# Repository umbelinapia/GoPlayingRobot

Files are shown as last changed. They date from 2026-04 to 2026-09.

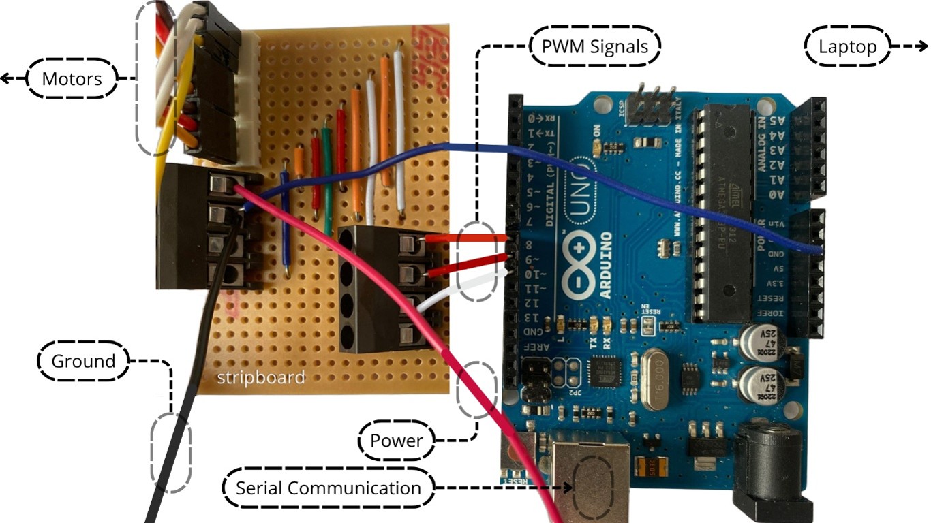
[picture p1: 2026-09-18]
evidence/labeled_arduino_stripboard_wiring.jpg

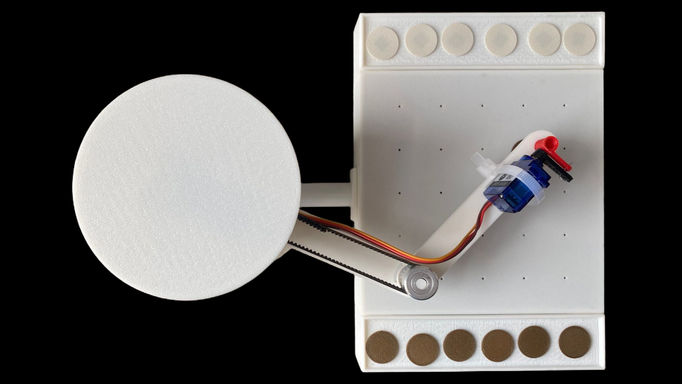
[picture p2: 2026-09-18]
evidence/robot_top_view_2.png

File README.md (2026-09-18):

# 3rd year Individual Project

## Project aim 
This report aims to build an autonomous robot that can master the ancient game of Go. This report focuses on designing, building, and validating a 3-DOF mechatronic robotic arm pick-and-place subsystem capable of reliably moving standard Go stones between specified board locations, using a defined coordinate interface and motion control.

## Project Objectives
1. Design and build a complete 3-DOF robotic arm electro-mechanical assembly, including CAD, actuator selection, mounting and joint structures capable of reaching all positions within the defined planar workspace.
2. Design and build a Go-stone gripper including its actuator, mounting interface to the arm, and required electrical connections capable of reliably picking up and placing Go stones.
3. Implement inverse kinematics to convert board coordinates into joint angles, enabling the end-effector to reach target positions within a positional accuracy of approximately 2 mm.
4. Develop and implement an interactive graphical user interface that converts user input into structured commands, transmitted to the motion controller under a second for execution in real-time.

## Board Interface
1. Clone the repository
2. Navigate to the python scipts Inside the software folder
3. Install dependencies listed in requirements.txt
4. Run the main code for the interface

## Motion controller
Upload `software/Arduino sketch/routines.ino` to your Arduino board using the Arduino IDE.

NOTE
Arduino Cloud sketches can also be found here:

🔗 https://app.arduino.cc/sketches/9923f9a1-adf1-4cbb-a925-ab8f35f5f6f3?view-mode=preview

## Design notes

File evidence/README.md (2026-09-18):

# Evidence

Supporting media for the Go-playing robot project: CAD renders, assembly photos, wiring diagrams, GUI screenshots, and design/flow diagrams. Imported from the local "supporting media content" folder.

| File | Label / Description |
|---|---|
| `wiring_diagram_arduino_servos.png` | Wiring schematic: Arduino Uno on a breadboard powered by USB (serial) and a separate 6V supply, driving three servos (Joint 1, Joint 2, Joint 3) via PWM, with a color-coded legend for ground, power, PWM signal, and serial lines. |
| `labeled_arduino_stripboard_wiring.jpg` | Photo of the real Arduino Uno wired to a stripboard, annotated with labels for Motors, PWM Signals, Laptop (USB), Ground, Power, and Serial Communication. |
| `system_block_diagram.png` | Hardware architecture block diagram: Python GUI sends serial commands over USB to the Arduino Uno, which sends PWM signals to the SCARA robot's three servos (Servo 1, Servo 2, Gripper servo); a separate power supply (gated by an emergency switch) powers the robot, which acts on the Go environment (board, bowls, stones). |
| `software_dataflow_diagram.png` | Software data-flow diagram showing three stages: (1) Graphical User Interface user input, (2) Arduino control system (command parsing → task logic → coordinate mapping → inverse kinematics → joint angles), (3) Output actuation to Servo 1, Servo 2, and the gripper servo. |
| `command_flowchart.png` | Logic flowchart for processing a `letter-number-letter` command (e.g. `B3P`), branching on the trailing R (release/place stone) or P (pick stone) code and on space/stone availability to the left or right, ending in `return to standby`. |
| `cad_dimensioned_cross_section.png` | Dimensioned CAD cross-section drawing of the arm/base assembly with key measurements in mm (110, 90, 140, 44, 22, 32, 10.5). |
| `robot_isometric_view.png` | Isometric photo of the fully assembled robot: cylindrical rotating base, boom arm with pulley/belt drive, gripper servo with magnetic end-effector, board with rows of stone slots, and a battery pack in a drawer under the base. |
| `robot_top_view_1.png` / `robot_top_view_2.png` | Top-down photos of the assembled robot in two arm positions, showing the rotating base disc, timing belt/pulley drive along the boom, and the blue micro servo end-effector positioned over the stone board. |
| `pulley_belt_closeup.png` | Two close-up shots of the GT2 timing pulley and belt at the arm's rotating joint. |
| `gripper_servo_horn_positions.png` | Side-by-side photos of the gripper servo horn at three rotation angles, showing the end-effector's release / neutral / pick-up positions. |
| `labeled_component_overview.png` | Annotated photos identifying the robot's main parts: Casing, Bowl, Stone, Timing belt and pulley, End-effector, and Power switch. |
| `low position.png` / `mid position.png` / `high position.png` | SolidWorks cross-section views of the vertical plunger/rod at its three stroke positions (fully lowered, mid-stroke, fully raised) within its housing. |
| `side slit view in casing.png` | SolidWorks assembly cross-section (side view) showing the full internal layout: servo stack, drive shaft, belt/pulley, and linkage inside the casing. |
| `go_gui_empty_board.png` | Screenshot of the "Responsive 5x5 Go Board" Python GUI with an empty board and the Arduino connection shown as ENABLED / "Sending to robot". |
| `go_gui_board_with_stones.png` | Screenshot of the same GUI mid-game, with black and white stones placed on the board and the Arduino link still ENABLED. |
| `target_coordinates_plot.png` | Plotted coordinate map (mm) of board target points, bowl target points, and the origin (0,0), with board and side-bowl outlines, used for the robot's placement coordinate calibration. |

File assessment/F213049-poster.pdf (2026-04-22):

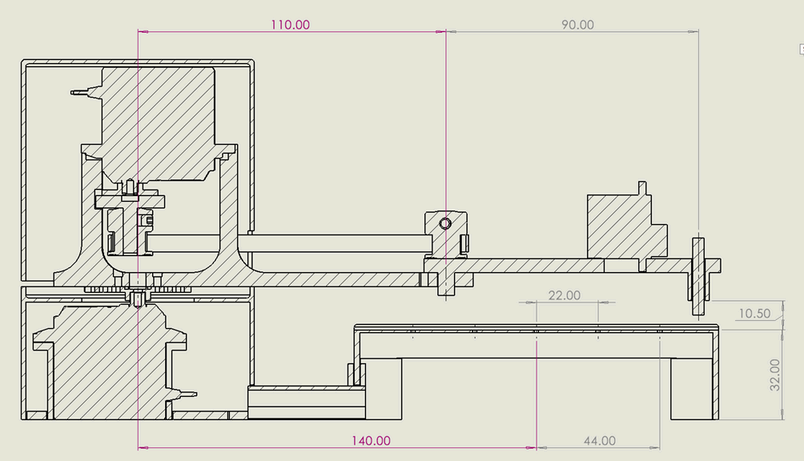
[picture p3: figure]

Design and build a complete 3-DOF robotic arm electromechanical assembly capable of reaching all 25 board positions within the planar workspace.
Design and build a Go-stone gripper capable of reliably picking up and placing stones.
Implementinverse kinematics converting board coordinatesto joint angles with ≈ ±2mmpositional accuracy.
Develop an interactive graphical user interface transmitting commandsto themotion controllerin under one second.

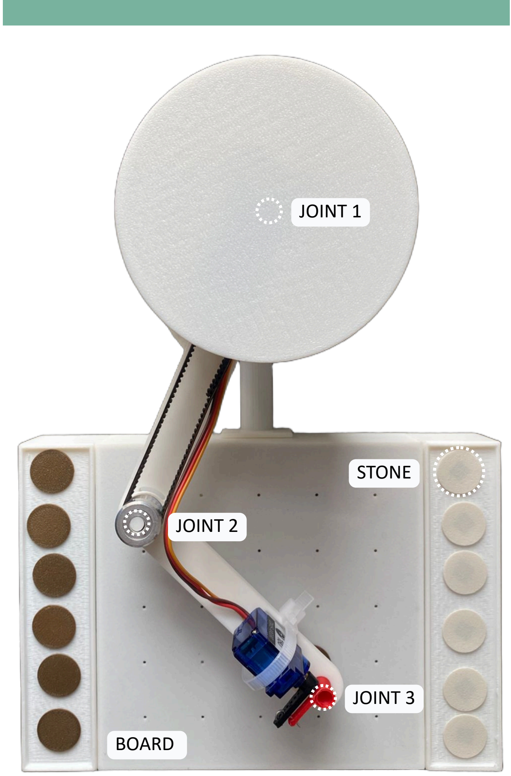
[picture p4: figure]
JOINT 1; JOINT 3; BOARD; STONE; JOINT 2

PLA deformation → slack and backlash → low accuracy Open-loop control → no feedback → no correction Limited workspace → 2 unreachable positions
Magnetic gripper → standardGo stonesincompatibility limited verticalrange → standardGo stonesincompatibility

3-DOF SCARA robotic armwith RRP joint configuration. Controlled by anmicrocontroller, operated through aGUI.Joint 2 is operated remotely with a timing belt and pulley drivingmechanism. Robot is at a fixed distance fromthe board.

Despite the resurgence of physical board games, a fundamental barrier persists: you need another player. Research shows physical materiality is a key part of the game experience that digital formats cannot replicate. Drawing upon those challenges, this report aims to build an autonomous robot that can master the ancient game ofGo.

It is an ancient Chinese board game conceived more than 2,500 years ago. The goal is to capture more territory than your opponent. The players do so each in turn by placing stones on the intersections of the board. the board can vary in size but the game is commonly played on a 19x19 board. It has very simple rules and concepts, and yet it is considered by many people to be the world’s greateststrategic game.

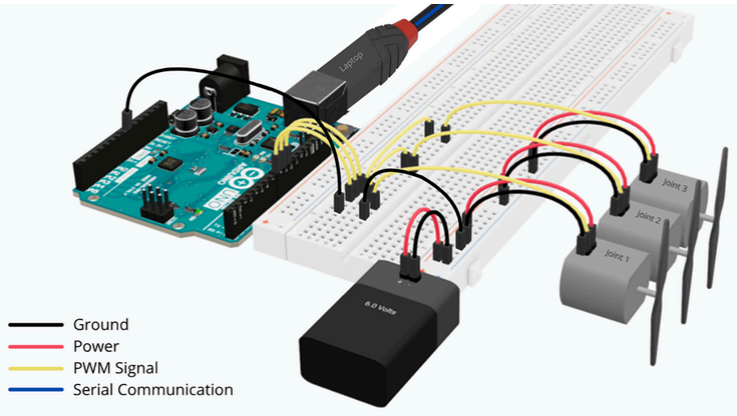
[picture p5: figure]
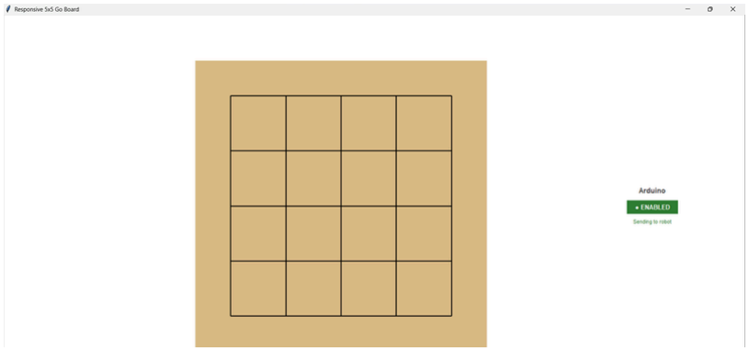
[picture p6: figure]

1.Computer vision forreal-time board state detection 2.Go AI engine integration forfull autonomy 3.Closed-loop feedback controlto improve precision 4.Redesigned end-effectorforstandardGo stones

P U R P O S E | M OT I VAT I O N

# S P E C I F I C AT I O N S

# A R C H I T E C T U R E

# C I R C U I T

# U S E R I N T E R FA C E

# E N D - E F F E C TO R

# R E S U LT S

L I M I TAT I O N S | F U T U R E W O R K

100% pick successrate achieved under controlled conditions (end-effector directly above stone)
Positional accuracy varied due to backlash atJoint 2 ,the ±2mm target was not consistently achieved Adjustablemotion speed via Arduino,set asslow
All 25 board intersectionsreached within defined workspace
links | lengths | joints | range | type | motor
Link 1 | 110mm | Joint 1 | 270° | revolute | DSS-M15S
Link 2 | 90mm | Joint 2 | 270° | revolute | DSS-M15S
Link 3 | 15mm | Joint 3 | 5mm | prismatic | DMS-MG90

# W O R K F LO W

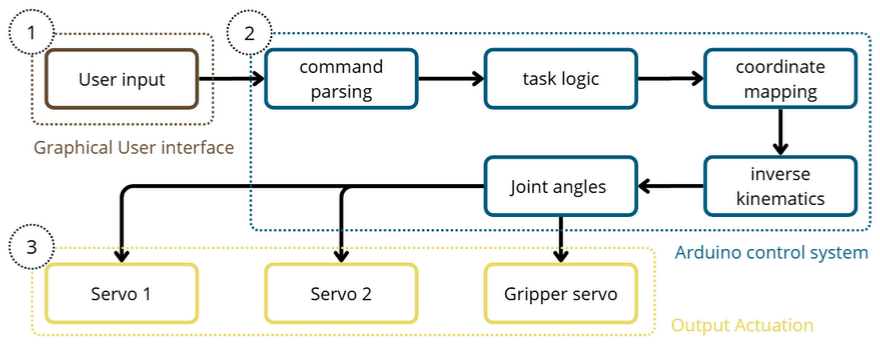
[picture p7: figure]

1.User clicks a board intersection on the PythonGUI
2.GUI formats a command (e.g. B3P = column B,row 3, Place) 3.Command sentto Arduino viaUSB serial communication 4.Arduino parses command and determines action 5.Targetmapped to Cartesian coordinates
6.Inverse kinematics computesjoint angles
7.PWM signalssentto servos, armmoves and executestask

A Python Tkinter graphical user interface was developed to control the robotic arm. The interface displays an interactive 5×5 Go board. The user places or removes stones by left or right clicking on board intersections. Each click generates a serial command (e.g. B3P)transmitted instantly to the Arduino.

Three servo motors are controlled by an Arduino Uno via PWM signals. Each servo is powered by an external 6V AA battery supply, with a common ground shared between the Arduino and power supply. Permanent connections are soldered to a stripboard to ensure reliability. The Arduino connectsto the laptop viaUSB forserial communication with theGUI.

# D E V I C E

# ProjectGrandmaster: An Autonomous RoboticOpponentforGo

### Robotics, Mechatronics and Control Engineering MEng 25WS50META Supervised by Massimiliano Zecca Wolfson School of Mechanical, Electrical and Manufacturing Engineering

Figure 2: End-effector Mechanism | Figure 1:Go Playing Robot

### WHAT ISGO?

### WHYDO WENEEDA ROBOT?

### WHAT ARE THEOBJECTIVES?

This report aims to build an autonomous robot that can master the ancient game ofGo.

### WHAT IS THE AIM?

Figure 4: SystemCircuit Model

Figure 3: System Workflow

Figure 5: GUI BoardDisplay

The end-effector combines Joint 3 and the gripping mechanism into a single unit. A servo converts angular motion into vertical movement via a horn and thin rod. Atthe bottom sits a permanent magnet for passive gripping of magnetic Go stones. It operates in three states:

(a) Low: picking position
(b)Hover: carrying/travelling position (c)High: dropping position

Table 1: Robot Specifications

Figure 6: Slice of Assembly Drawing

Umbelina Pia Selva F213049

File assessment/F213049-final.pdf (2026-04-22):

Wolfson School of Mechanical, Electrical and Manufacturing Engineering

## Individual Project Final Report

ID Number: F213049

Programme: Robotics, Mechatronics and Control Engineering

Module Code: 25WS50META

Project Title: Project Grandmaster: An Autonomous Robotic Opponent for Go.

Abstract:

This report presents the design and implementation of an autonomous robotic system capable of acting as a partial physical opponent for the board game Go. The primary aim was to develop a 3 degree of freedom SCARA based robotic arm capable of reliably performing pick and place operations of Go stones on a Go board.

The system was brought to life through a combination of mechanical design, hardware implementation and software control. A SCARA configuration was selected for its suitability in such tasks, and the robot was made to meet workspace and precision requirements. Forward and inverse kinematics were explored to compute joint angles from board coordinates. Control was achieved using a micro controller, with formatted commands converted from the user input by a Python Graphical User Interface.

The robot demonstrated reliable operation across the defined workspace. It achieved consistent pick and place operations with the gripper, reaching 100% success rate under specific conditions. With an efficient inverse kinematics algorithm, the system maintained good repeatability throughout experiments. However, the system suffered minor precision errors due to mechanical backlash. Additional limitations included lack of feedback control and flexibility of the device.

In conclusion, the project achieved its objective of developing a functional robotic Go opponent at a low-level. While the output has successfully met most objectives, the integration of computer vision and an AI Go engine is required to achieve full autonomy.

## 1 Table of Contents

## 2 Introduction

2.1 Project background
Amongst many other board games, the game of Go stands out for its ancient origins. Go, as it is known in Japan, is an ancient Chinese board game conceived more than 2,500 years ago [1], and it is believed to be the oldest board game that is still played today. Also known as Weiqi (圍棋) in China meaning "surrounding game", the goal is to capture more territory than your opponent. The players do so each in turn by placing stones on the checkered lines of the board. Although, the board can vary in size depending on the level of the player, the game is commonly played on a 19x19 board. It has very simple rules and concepts, and yet it is considered by many people to be the world’s greatest strategic game, far surpassing Chess in its complexity [2]. It was brought to the UK from Japan over a century ago and has since gained in popularity.

2.2 Project context
Developments in technology have progressively shifted board games, such as Go, on digital platforms. Modern video games offer many advantages over board games. Players can instantly access a wide variety of games at any time and connect with opponents globally without the constraints of location or time. However, there has recently been renewed interest in physical board games. This resurgence in popularity has led to their increasing commercial success [3]. Despite this rising phenomenon, there remains a paucity of evidence on the reasons why players would rather choose board games over online ones. It is important to note that the relative preference of board gaming is debated in the literature. It can be argued that playing on a physical board offers a tactile and sensory experience sought by players. Recent evidence shows that the materiality provided by physical components is a key element in the player experience that digital formats cannot replicate [4]. On the other hand, board games also present serious drawbacks. The main limitation lies in requiring another player. Players often find themselves unable to engage with board games particularly when no suitable opponent is available. This creates a challenge, leading many to seek a form of the game that combines the advantages of both physical and digital versions. Restoring the authenticity of board games whilst no longer relying on the presence of a fellow player. A solution that can provide a constant, capable and physical opponent allowing the gaming experience to be enjoyed to its fullest.

2.3 Project aims and objectives
Drawing upon the challenges associated with board games, this report aims to build an autonomous robot that can master the ancient game of Go. This report focuses on designing, building, and validating a 3-DOF mechatronic robotic arm pick-and-place subsystem capable of reliably moving standard Go stones between specified board locations, using a defined coordinate interface and motion control. It is beyond the scope of study to encompass the implementation of an intelligent computer vision system with a powerful, pre-existing AI game engine.

The main objectives of the project were to:
1. Design and build a complete 3-DOF robotic arm electro-mechanical assembly, including CAD, actuator selection, mounting and joint structures capable of reaching all positions within the defined planar workspace.
2. Design and build a Go-stone gripper including its actuator, mounting interface to the arm, and required electrical connections capable of reliably picking up and placing Go stones.
3. Implement inverse kinematics to convert board coordinates into joint angles, enabling the end-effector to reach target positions within a positional accuracy of approximately 2 mm.
4. Develop and implement an interactive graphical user interface that converts user input into structured commands, transmitted to the motion controller under a second for execution in real-time.

2.4 Report description
This report begins with a brief literature review, examining related work in the field and possible robot architectures fit for this project. It then proceeds to the main body, which is organised into four chapters. The first section of this report will examine the model of the system including design constraints, overall structure, links and joints, kinematic model, and inverse kinematics of the robot. The second part will be concerned with the hardware of the project. Specifically, the selection and development of key components such as the CAD links, actuation system, transmission mechanism, end-effector, power supply, and control hardware. Chapter three will begin laying out the implementation of the control system, including the Arduino setup, and it looks at how the target coordinates are mapped, movement sequences operated and serial command handled. This is followed by the description of the Python-based playing interface as well as the workflow of the overall system. The last section will present the results of the project, focusing on the limitations and considering the possible future developments of the project.

## 3 Literature review

3.1 Related work
Whilst some research has been carried out on other board game playing robots, only a limited number of Go playing robots have been identified. One of which is a commercialised device, called senseRobot [5]. It features an AI engine integrated in a robotic arm, which provides a learning platform for beginners and children. The robot also covers a wide variety of other board games such as Gomoku, Xiangqi and chess. Similarly, a great deal of previous research into board game playing robots has focused on chess [6,7,8,9,10,11]. A number of these studies focus on the implementation of a chess engine with a robot, that has not been designed for chess, to offer a physical opponent. In order to deliver the task some of the researchers have opted to work with either a Cartesian robot, a custom 6 DOF robot, or a collaborative UR5 robot. Despite having different mechanical structures, these systems share the same components, automatic detection and recognition of the board enabled with a vision system and learning algorithms. Such approaches are relevant because chess, like Go, is an ancient board game played on a wood board around the same size. However, these studies have failed to address the inclusion of a Go stone specific end-effector and the implementation of a Go engine in a manipulator. A search of the literature revealed studies which cover Go engines alone [12,13]. The algorithms use reinforcement learning to play against opponents and are deployed on board games interfaces when facing a physical player. Their performance is unmatched compared to human’s success rate and reach levels far beyond worldwide professional players. But up to now, far too little attention has been paid to implement these same AI agents into a physical game-playing robot. Many hobbyists have attempted to bridge the gap however none of them qualify as academic peer reviewed papers and therefore this idea has received scant attention in the research literature.

3.2 Robot architecture
Given the lack of groundwork for Go playing robots, plenty of freedom is given with regards to the mechanical design. From a mechanical perspective, the system can be fundamentally characterized as a pick and place device. Research has been led to better understand the mechanisms of different robotic structures and their underlying advantages depending on the required task [14,15,16]. These studies offer a classification of robotic architecture and their uses. They suggest that there are five main robot types: cylindrical, articulated, SCARA, Cartesian and Delta robots among many others. Out of which, three configurations emerge from the studies mentioned so far used to perform pick and place operations: specifically, the SCARA, Delta and Cartesian robots. There seems to be some evidence to indicate they supply high speed and good repeatability making them ideal for such tasks. A number of studies have postulated that Delta robots despite having low payload capacities and a small workspace, have extremely high-performance speed and precision [17,18,19]. These aspects theoretically lend themselves well for picking and dropping stones on a board. However, their parallel-link structure introduces significantly greater kinematic complexity compared to other configurations, making both implementation and control more challenging. In contrast, other writers have adopted Cartesian architectures instead [20,21,22]. Together these studies provide important insights into the benefits and downsides of this configuration. Cartesian robots have proven to be equally good in both speed and precision. Additionally, it is noted that their rigid axis allows them to sustain much higher loads. However, this comes at the price of size, which impairs the workspace and in turn limits the reach of the end-effector. Although the dynamics fit the gameboard narrative well, in a Go game setting, the rigid axes might interfere with the human opponent’s personal space while playing. Along the same lines, many recent studies have also shown that SCARA robots are ideal for pick and place purposes[23,24,25]. Their work demonstrates that this configuration is consistent with previous ones, showcasing high speed and precision especially for planar tasks, with a moderate payload capacity. Such characteristics make them highly effective for Go-based tasks, which are performed over a flat even surface. However, there are noted flaws in the vertical axis, having limited reach and low flexibility. But these constraints are acceptable for the current application, where motion is largely planar and height variation is minimal. Overall, SCARA robots provide a more compact and accessible design than Cartesian systems, and a simpler, more practical implementation compared to Delta configurations. In all the studies reviewed here, precision is recognised asthe key indicator for pick and place tasks. Given all the design trade-offs, cost and existing literature on Go playing robots, considerable evidence has accumulated to show that SCARA robot structures are best suited for this project.

## 4 Methodology

4.1 Model

4.1.1 Constraints
To inform the design of the SCARA robot, the physical dimensions of the board and stones were identified, as these defined the system requirements. It should be noted that, for the purposes of this project, Go related materials were homemade and therefore did not fully reflect traditional designs. This project is focused on the second smallest Go board size, a 5x5 Go board. Each twenty-five playable position on the board was an intersection of a grid formed by a windowpane pattern. The board dimensions were as follows 130 mm in width and length, with row spacing of 23 mm and column spacing of 22 mm, resulting in a slight asymmetry. The Go stones used in this project have a diameter of 18.0 mm and are 1mm thick, resulting in a negligible mass. This is important because weight of the Go stones and their dimension influenced directly the design of robot and its the end-effector. Additionally, stones were stored in bowls during gameplay, which has been considered in this design.

Based on these constraints, the manipulator was required to have a minimum reach of at least 135 mm to fully cover the board. Furthermore, the robot was required to achieve a precision ±2 mm to accurately pick and drop stones at specific intersectionsin order to avoid overlapping stones. Finally, it was required to have a minimum vertical range of 5 mm to allow for clearance above board and stones during manipulation, meanwhile payload requirements remained minimal.

4.1.2 Structure
To cater for all constraints, the adopted design conformed to a SCARA-based structure with an open kinematic configuration. The robotic arm consisted of a series of links connected by three joints, forming an open-kinematic chain. One end of chain was connected to the base, while the other end was equipped of an end -effector to manipulate Go stones [Fig 1]. The system followed an RRP joint configuration which provided three degrees of freedom. The two first joints were revolute, enabling rotational motion, while the third one was prismatic, providing linear motion [Fig 2]. This arrangement enabled planar motion in the horizontal plane combined with vertical motion for picking and dropping stones.

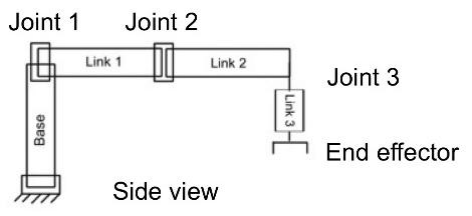
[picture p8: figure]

4.1.3 Links and joints

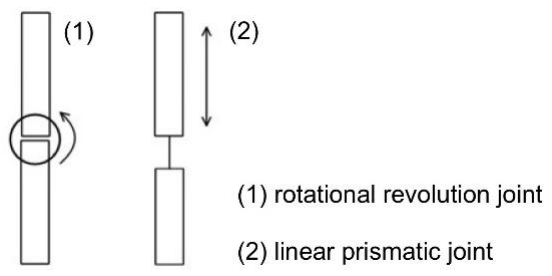
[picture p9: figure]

The manipulator workspace was determined by the number of joints, their geometric arrangement, and the link dimensions. In this design, the link lengths were selected to ensure that the robot can

Figure 1: Scara robot configuration | Figure 2: Joint configurations

cover the full board. The combined lengths of the two first links allowed the wrist frame to reach all twenty-five intersections. Additional length in the links was considered for the robot base to be positioned at an offset from the board rather than directly adjacent to it. Overall, the link lengths were chosen to maximize reachable workspace while keeping the structure compact and reducing the torque required for each revolute joint.

For the first two links, the planar RR reachable workspace, where r the distance from the base to the end-effector, was:

∣ L1 − L2 ∣≤ r ≤ L1 + L2 | 20 ≤ r ≤ 200 mm

The model reached points at distances between 20 mm and 200 mm from the base. Only the offset between the base and the board would determine whether the intersections are within the reachable workspace. As it were, the base frame of the robot stood 140mm away from the centre of the Go board. As a result, any desired target point on the board lied within the reachable workspace of the manipulator. To maximise the workspace, each revolute joint was designed with a rotational range of 270° [Figure 3], allowing the manipulator to access a wider set of positions such as the stones contained in the bowls.

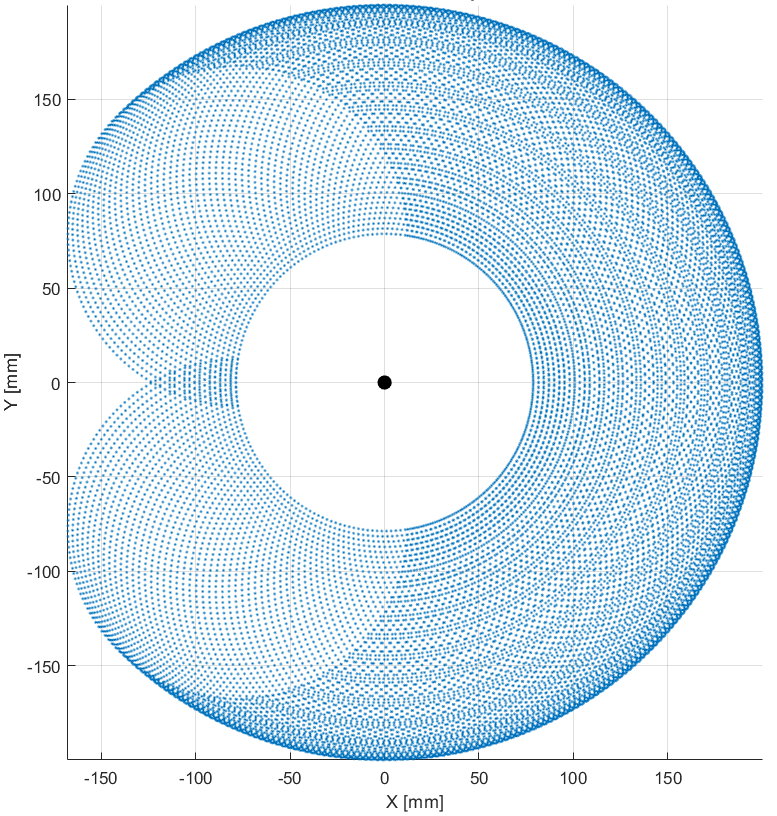
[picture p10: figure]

Figure 3: Reachable workspace

Table 1. Dimensions

Links | Lengths | Units | Joints | Range | Units
1 | 110 | Millimetres | 1 | 270 | Degrees
2 | 90 | Millimetres | 2 | 270 | Degrees
3 | 15 | Millimetres | 3 | 5 | Millimetres

4.1.4 Kinematics
Given a set of joint angles, the position and orientation of the tool frame relative to the base frame of the manipulator were computed using forward kinematics. The composition of the link parameters of the open-chain manipulator was as follows:

The position of the wrist frame relative to the base frame was expressed as:

x = L1 cos(θ1

) + L2 cos(θ1 + θ2

) = 110 cos(θ1

) + 90 cos(θ1 + θ2

)

y = L1 sin(θ1

) + L2 sin(θ1 + θ2

) = 110 sin(θ1

) + 90 sin(θ1 + θ2

)

z = 50 − d3

The overall transformation from the base frame to the tool frame was obtained by multiplying the homogeneous transformation matrices of each joint:

T0

3 = [

cos(θ1 + θ2

) − sin(θ1 + θ2

) 0 L1 cos(θ1

) + L2 cos(θ1 + θ2

)
sin(θ1 + θ2
) | cos(θ1 + θ2
) | 0 | L1 sin(θ1

) + L2 sin(θ1 + θ2

)
0 | 0 | 1 | 50 − d3
0 | 0 | 0 | 1

]

Where:

L1 = 110mm

L2 = 90mm

T0

3 = [

cos(θ1 + θ2

) − sin(θ1 + θ2

) 0 110 cos(θ1

) + 90 cos(θ1 + θ2

)
sin(θ1 + θ2
) | cos(θ1 + θ2
) | 0 110 sin(θ1

) + 90 sin(θ1 + θ2

)
0 | 0 | 1 | 50 − d3
0 | 0 | 0 | 1

]

Table 2. DH parameters of SCARA robot

Link number | Link length [mm] | Twist angles | Link offset [mm] | Joint angles
i | ai | αi | di | Θi
1 | 110 | 0 | 50 | Θi1
2 | 90 | 0 | 0 | Θ2
3 | 15 | 0 | d3 | 0

4.1.5 Inverse Kinematics
Inverse kinematics was used to determine the joint variables required for the manipulator to reach a desired position in the task space. In this project, inverse kinematics was applied to map the intersections of the Go board into corresponding joint space configurations. For this purpose, only the first two joints were considered, as they fully defined the position in the xy-plane. The third joint did not influence planar motion and was therefore omitted in the analysis.

Let the desired wrist position be (x,y). The radial distance from the base was:

r

2 = x

2 + y

2

Using the law of cosines, the second joint angle was given by:

cos(θ2

) =

r

2 − L1

2 − L2

2
2L1L2

θ2 = arccos (
r

2 − L1

2 − L2

2
2L1L2

)

The first joint angle was then obtained as:

θ1 = atan 2(y, x) − atan 2(L2 sin(θ2

) , L1 + L2 cos(θ2

))

Two possible solutions existed for θ1 and θ2, corresponding to the elbow-up and elbow-down configurations of the manipulator. Both solutions were valid as they lied within the joint limits.

4.2 Hardware

4.2.1 Links CAD and 3d printing
To put all those theoretical calculations into practice and bring the SCARA robot to life, the system was designed to meet the defined requirements. The parts required to achieve the desired link lengths were designed using SolidWorks and manufactured using Bambu Studio on Bambu 3D printers. They were manufactured using PLA due to its ease of printing, low cost, and sufficient stiffness for the low-load application. The links were designed as lightweight rectangular beams [Figure 4] to provide sufficient stiffness while minimising mass. Thereby reducing the torque required at each joint, allowing for smaller and more efficient actuators. The masses of the individual links were determined to be 18g, 10g, and 1g for links 1, 2, and 3 respectively. All parts of the assembly model can be found in the appendix.

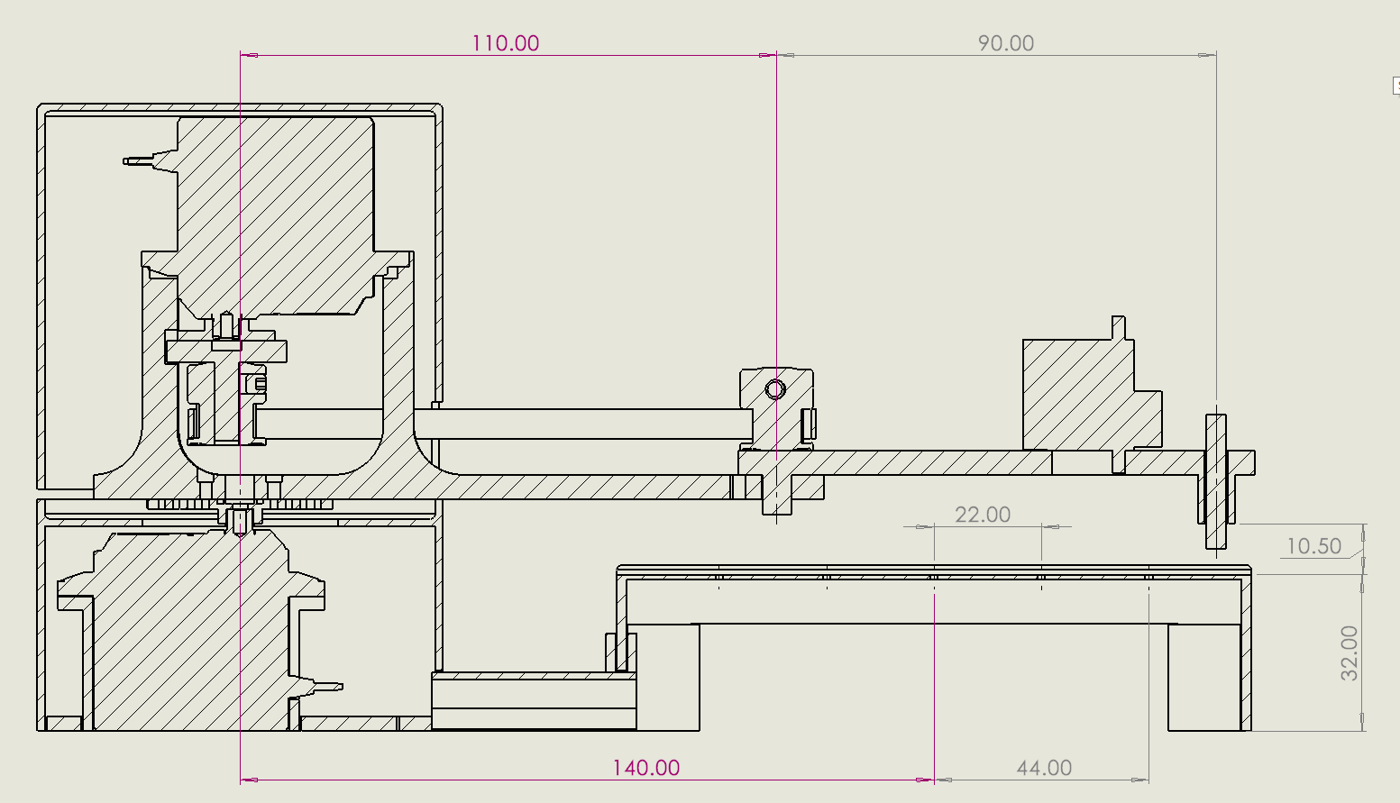
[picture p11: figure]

Figure 4: Assembled CAD Side view

4.2.2 Actuation system
The selection of actuators was guided by the torque and range of motion required for the manipulator. For a robot joint, the required torque is the sum of the moments caused by all loads acting beyond that joint [equation 1]. τ is the torque and d represents the perpendicular distance from the joint axis. F is the sum of all the forces acting on an object, and g the gravitational force. In this case, the main force acting on the arm was the weight :
τ = F ∗ d | F = m ∗ g | τ = m ∗ g ∗ d

For joint 3, the mass of the combined end-effector and payload was negligible therefore only a small torque was required [Tab 4]. However, the same could not be said for joint 1. The static torque required at joint 1 was estimated from the masses of the links, end-effector, and payload, along with their distances from the joint axis. It was calculated as follows:

τ1 = m1 ∗ g ∗

L1
2

+ m2 ∗ g ∗ (L1 +

L2
2

) + m3 ∗ g ∗ (L1 + L2)

Where:
m1= mass of Link 1 and the motor at Joint 2 = 18 + 72 = 90 grams
m2= mass of Link 2 and the pulley at Joint 2 = 10 + 10 = 20 grams
m3= mass of Link 3, the servo at Joint 3, and the end-effector magnet = 1 + 9 + 2 = 12

τ1 = 90 ∗ g ∗

110
2

+ 20 ∗ g ∗ (110 +

90
2

) + 12 ∗ g ∗ (110 + 90) = 1.05 kg ∗ cm

The selected actuator provided a stall torque of 11.5 kg*cm. This provided a sufficient safety margin for reliable operation while accounting for friction and assembly tolerances. The same actuator was selected for joint 2, where the torque requirements were lower. Additionally, these motors were chosen to satisfy the desired operating range of 270 degrees.

Table 3. Actuator selection

Model | Type | Weight | Stall Torque | Operating Voltage | Operating Range
DMS-MG90 | Servo | 9g | 1.8 kg / cm | 4.8-6V | 60° degrees
DSS-M15S | Servo | 72g | 13.5 kg / cm | 4.8-7.2V | 270° degrees

4.2.3 Transmission mechanism
To reduce the load acting on Joint 1, the actuator responsible for driving Joint 2 was positioned above Joint 1 rather than directly on Link 1. As a result, a transmission mechanism was required to transfer motion from the motor to joint 2 remotely. To achieve this, a timing belt and pulley system was implemented to the design. To maintain 1:1 transmission ratio and ensure that angular displacement was directly transferred from the motor to joint 2, identical GT2 models with a diameter of 12.22mm were used at both ends. This pulley profile was specifically designed to minimise backlash and provide accuracy. Finally, the centre distance between the two pulleys was set to 110 mm. Based on this configuration, the required belt length [eq 3] was calculated to ensure proper tension, reduce backlash and avoid poor transmission. This was particularly important given the precision requirements of the manipulator.

L = 2 ∗ C + 1.57 ∗ (D + d) +

(D − d)

2
4 ∗ dC = 258 mm

Where:
C = Centre to centre distance = 110 mm D = d = Diameter of pulley = 12.22 mm

L = Length of timing belt

4.2.4 End-Effector design
The end-effector featured both the Joint 3 and the gripping mechanism into a single unit. This design enabled the motor to perform both vertical motion and pick-and-place operations. The motor’s angular motion was converted into vertical motion via a servo horn through a thin rod connected to link 3. In which lay within, at the bottom, a magnet that carried out the ‘gripping’ operation [Figure 5]. It was a passive system which only complied with light magnetic stones. The end effector operated in three distinct states. The low position [a] where the end-effector was brought into contact with the stone, allowing the magnet to attract and pick it up. The hovering position [b] where the end-effector was raised slightly above the board, enabling safe horizontal transport of the stone without interference with other pieces. And finally, the top position [c] where the end-effector was lifted further upward, causing the stone to lose contact with the magnet.

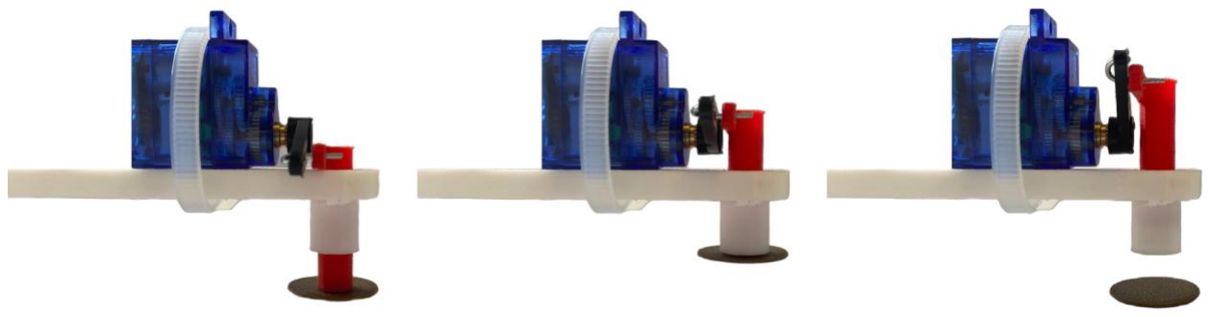
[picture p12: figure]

(a) Low | (b) Hover | (c) High

Figure 5: End-effector mechanism

4.2.5 Power supply
The system was powered by four AA batteries, providing a total supply voltage of approximately 6V. This voltage was suitable for driving the selected servo motors, which operated within a range of 4.8 to 7.2 V. The system could easily be powered on and off with the switch provided on the battery container.

4.2.6 Control Hardware
The servo motors were controlled by an Arduino Uno, which generated the required PWM signals to control the angular position of each joint. Each servo had 3 wires: power, ground and signal. The signal wire was connected to the Arduino via signal pins, while power and ground wires were supplied by the external power supply [Figure 6]. A common ground was maintained between the Arduino and the power supply to ensure proper signal reference. Lastly, the Arduino Uno was connected to a laptop via a USB cable, enabling the transmission of inputs from the playing interface.

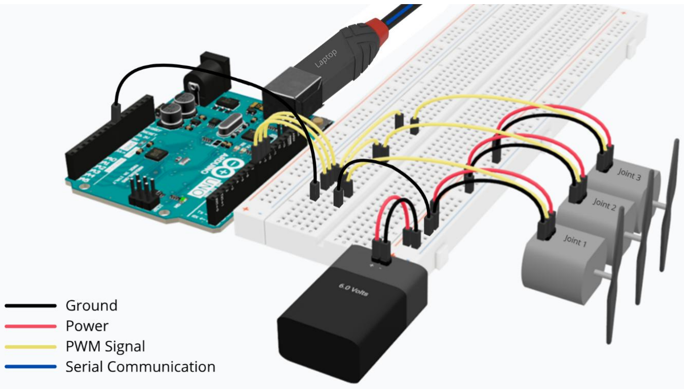
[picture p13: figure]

Figure 6: Circuit model

4.2.7 Circuit and assembly
The electrical system of the device consisted of three servo motors, an Arduino microcontroller, and a dedicated power supply. To ensure a reliable and robust circuit, the permanent connections were soldered to a stripboard. This reduced the risk of loose connections. Cable management was also considered in the design to reduce clutter and improve ease of transport. Routing paths were incorporated into the CAD model to conceal and secure cables within the structure [Figure 7].

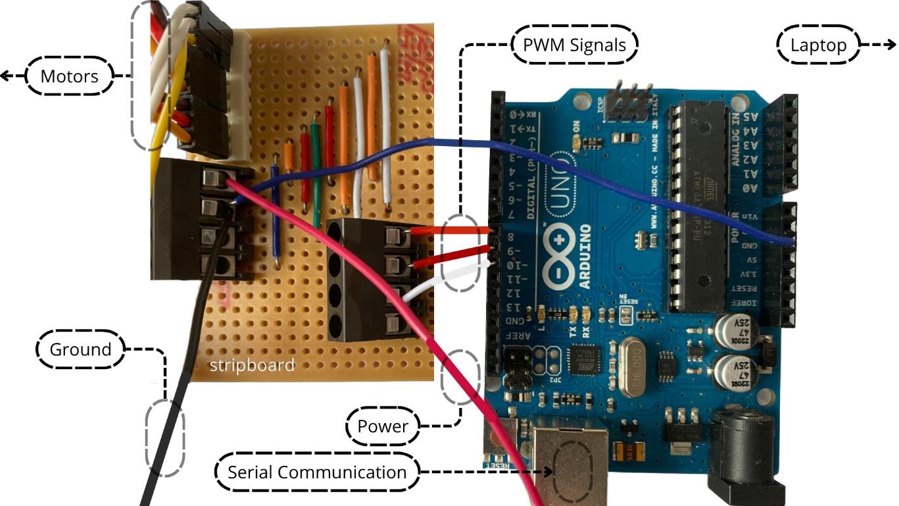
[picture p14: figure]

Figure 7: Circuit assembly

Finally, upon assembly, the components formed the complete SCARA robot system. The links, joints, and actuators were securely fastened using either cable ties, tight fits or screws and nuts. A casing was added to cover the components [Figure 8]. Although initially intended for visual appearance, the casing also contributed to the safety of the device.

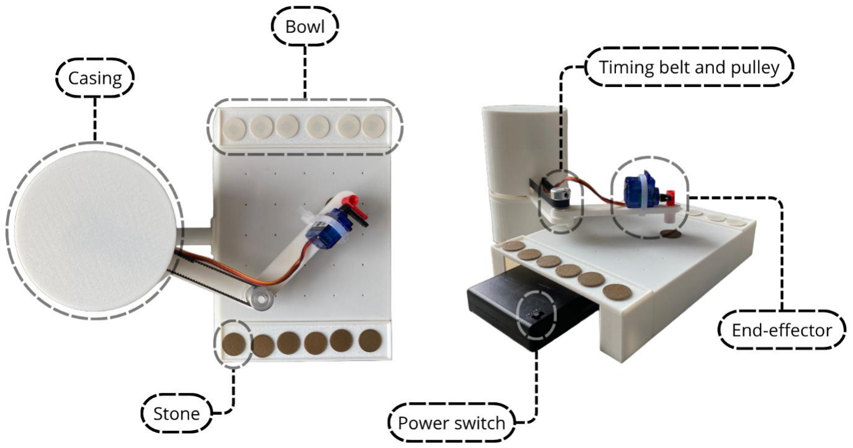
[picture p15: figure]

Figure 8: Go playing SCARA Robot

4.3 Software

4.3.1 Arduino IDE
To control the three motors connected, the SCARA robot was programmed using Arduino IDE. This environment was used to write, compile and upload code to the Arduino board as well as send commands through the serial monitor [Figure 9].

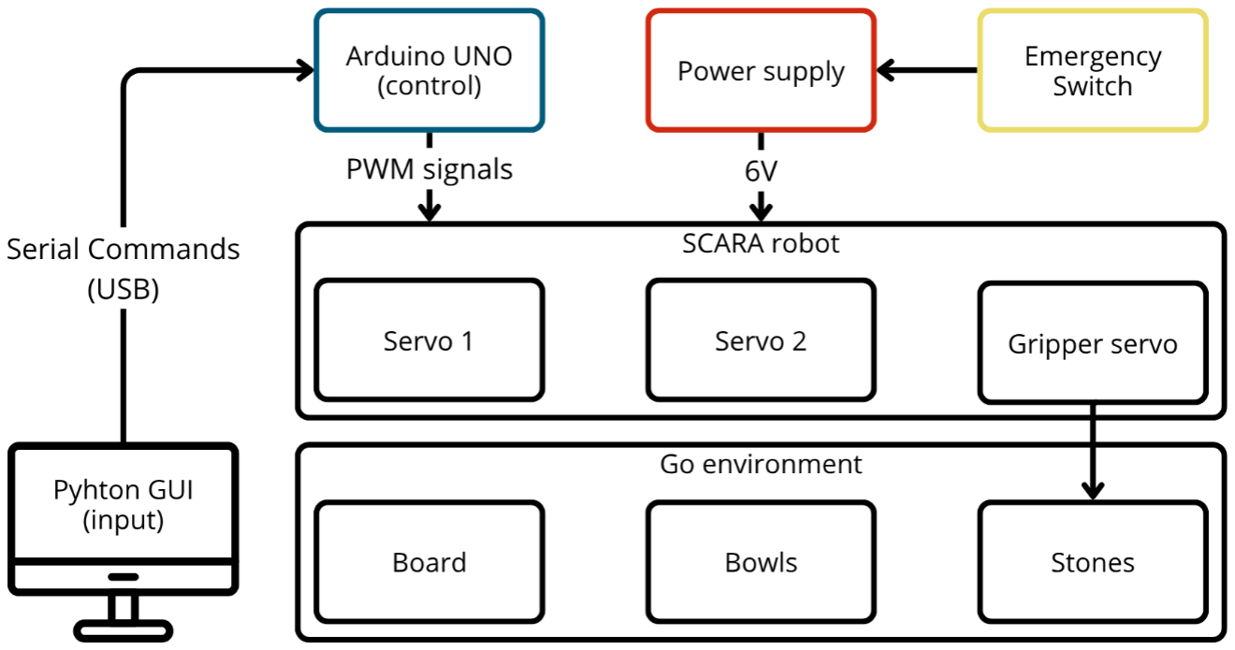
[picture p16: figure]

Figure 9: System Architecture

The project was separated into header files [Figure 10] to make the project easier to maintain and debug. In total, the folder consisted of seven files: the main Arduino .ino file and three pairs of .cpp (source) and .h (header) files. The .cpp files each contained a specific implementation, while the corresponding .h files declared functions and shared variables, making them accessible across different files. They can all be found in the appendix.

Figure 10: Project files

4.3.2 System setup
The main file provided the foundation for the rest of the environment. In included an inverse kinematics model was implemented to enable the robotic arm to reach specific target positions on the board. Before this could be applied, the required libraries were imported to support the mathematical computations needed to determine joint angles from a given set of coordinates. As multiple joint configurations can exist for a single target position, a consistent configuration was selected. The physical dimensions of the arm and the offset between the board frame and the robot base were defined to allow accurate transformation of target coordinates into the arm’s reference frame. The three servos controlling the joints and end-effector were initialised and assigned to specific Arduino pins [see Appendix], allowing the computed IK outputs to be translated into physical movement of the arm. In addition, serial communication was initialised in this file to allow target positions to be sent from the laptop to the Arduino, to be processed by functions described in a later section.

4.3.3 Target Coordinates
The coordinates file managed the representation and transformation of pre-defined target positions, supporting the inverse kinematics calculations. It included the description of the layout of the playing area. A predefined grid represented the board positions with 25 coordinates, while additional coordinate sets defined locations for the left and right bowls [Figure 11]. It also provided functions to convert user-friendly inputs into Cartesian board coordinates which are used by the inverse kinematics algorithm to generate the required joint movements.

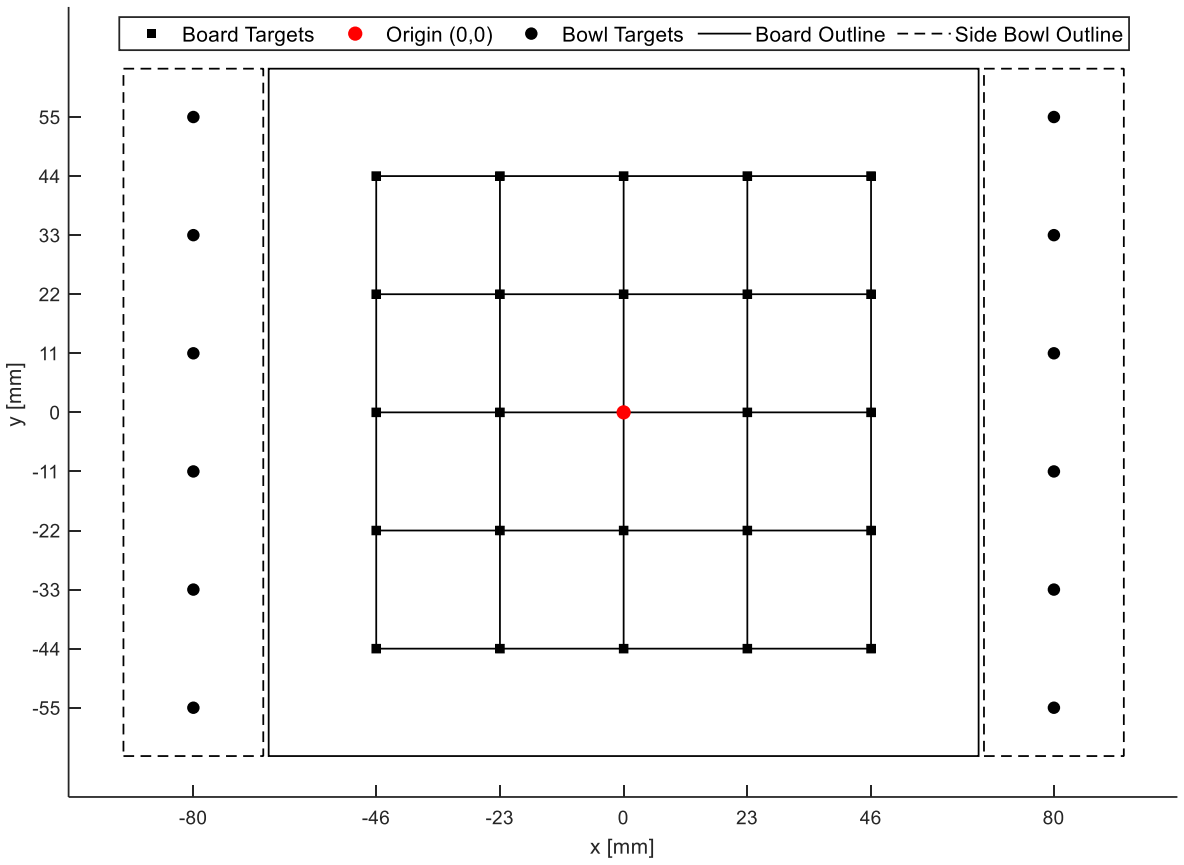
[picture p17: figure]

Figure 11:Cartesian coordinates of board and bowls

4.3.4 Sequences
The tasks file defined higher-level behaviours, grouping sequences of movements into executable actions. The two highest-level routines of the robotic arm defined are placing or removing stones from the board [Figure 12]. This script enabled the conversion of simple inputs into complete task sequences, involving both the end-effector and the joints. It also tracked the state of the left and right bowls on either side of the board, by recording which slots contained stones and which ones were empty. This allowed the system to automatically select valid pickup and drop-off locations during operation. While this file handled main routines, the following file took charge of the simpler ones which did not require consecutive steps.

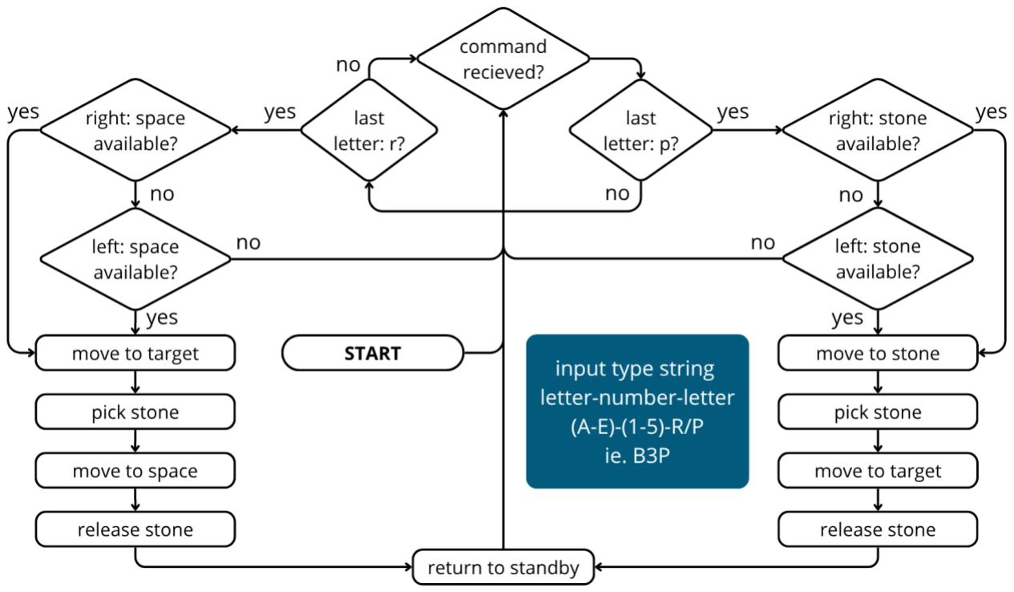
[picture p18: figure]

Figure 12: Arduino logic diagram

4.3.5 Serial commands
The commands file interpreted incoming commands from the serial monitor in real time. This script was essential as it acted as the middleman between the user input and the motion functions of the robotic arm. Not only did it read incoming serial data, interpreted the command format, and called the corresponding function to handle the data. It also, supported direct movement commands, predefined arm positions, end-effector controls, and the simple pick-and-place tasks. Moreover, it distinguished between board coordinates and storage box locations, allowing different parts of the workspace to be addressed through a simple command syntax. Input validation was included to reject invalid commands and provide feedback through the serial monitor.

4.3.6 Playing Interface
A graphical user interface [Figure 13] was initialised in Python using the Tkinter library to provide a way of controlling the robotic arm. This interface was used to effectively convert user inputs into commands that are interpreted by the Arduino system. To do so, the interface displayed an interactive 5×5 Go board, allowing the user to place or remove stones by clicking on board intersections, with either a right or left using any standard mouse or keypad. Each interaction updated the board display and generated a corresponding command, formatted as shown on Figure
13. Within the command string, the first character represented the column of the target on the board, the second represented the row, and the third indicated the action, either ‘P’ or ‘R’, corresponding to place or remove as defined in the Arduino system. Eventually, these commands were then immediately passed to the Arduino via serial communication.

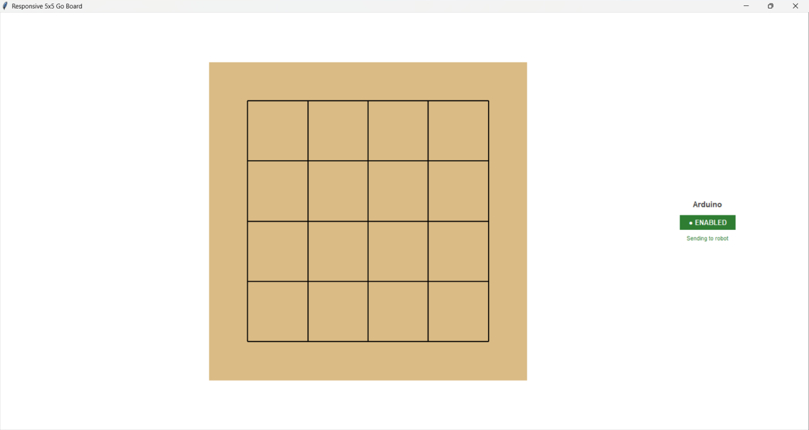
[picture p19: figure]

Figure 13: Graphical user interface display

4.3.7 Workflow
The process was divided into three main stages: user interface, control system processing, and actuation [Figure 14]. The workflow began with the user’s input through the Python-based graphical user interface. The player selected an intersection on the board. The selected target position was formatted into a command before being transmitted to the Arduino via serial communication. Upon receiving the command, the content was parsed. The Arduino determined the required action, such as placing or removing a stone. The selected target was then converted into Cartesian coordinates through coordinate mapping. These coordinates were passed to the inverse kinematics algorithm, which computed the required joint angles for the robotic arm to reach the desired position. Then the Arduino passed the corresponding PWM signals to the servo motors. Each servo executed the angular motion accordingly until the task was completed and the user satisfied.

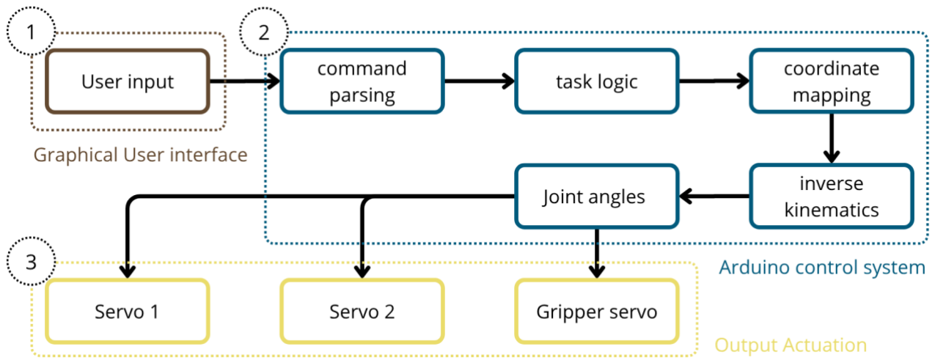
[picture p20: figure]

Figure 14: System workflow

## 5 Conclusion

5.1 Results
This report set out to design and implement a robotic system capable of autonomously performing pick-and-place operations on a 5×5 Go board. The objectives were successfully achieved with the integration of mechanical design, control software, and user interface.

A complete 3-DOF robotic arm was successfully designed and fabricated, including the CAD model, actuator selection, and mechanical assembly. The system operated as intended, with all joints functioning and capable of reaching the defined workspace. A functional gripper mechanism was developed and integrated with the arm. The gripper was able to pick, and place Go stones effectively using a magnetic approach with 100% success rate. Forward and inverse kinematics were successfully implemented, enabling conversion between joint space and end-effector position. The inverse kinematics solver reliably generated valid joint angles for reachable targets, while rejecting unreachable positions, contributing to overall system robustness. A command interface was implemented to accept board coordinates and actions (pick/place), which were transmitted via serial communication from the Python interface to the Arduino. These commands were successfully interpreted and converted into joint-space movements, enabling real-time control of the robotic arm.

Additionally, an emergency stop provided by the power supply switch allowed the system to be safely halted at any time by cutting power to the servos, further providing safety measures. In terms of performance, the system demonstrated good precision and repeatability, consistently returning to the same positions when executing identical commands. However, a slight positional error was observed at joint 2 during anticlockwise motion, which occasionally resulted in failed pickups (when the stone was outside the magnetic range) or slight misplacement, causing stones to overlap. The system showed generally good reliability, although an abrupt movement was observed each time the system was initialised with servos jumping to their zero positions. This undesirable behaviour was not managed and presents a potential safety concern. Finally, while the speed was slow, the system achieved satisfactory responsiveness, with smooth motion.

5.2 Limitations
The results of this project highlighted several limitations. The robotic arm operated within a limited workspace, constrained by the link dimensions and the range of motion of its joints. As it were, the uppermost locations in the storage bowls were not reachable. This limitation could have been addressed through redesign, for example by repositioning the bowls closer to the arm or modifying link lengths. Additionally, the system had restricted vertical motion. These constraints affected the system’s applicability to real-world scenarios. For instance, if used with a standard Go set, the current design would be unsuitable, as the stones are much taller. The gripper relied on magnetic attraction, whereas real Go stones are typically non-magnetic, making reliable pickup infeasible without redesigning the end-effector.

A key source of inaccuracy was identified at Joint 2, where slight positional errors were observed due to backlash in the transmission system. This backlash was likely due to the use of PLA which suffered deformation under tension. This deformation reduced belt tension by slightly decreasing the distance between pulleys, increasing slack and therefore amplifying backlash. This issue could have been mitigated through improved mechanical design. However, its impact was exacerbated by the fact that the system operated in an open-loop configuration. As the current design does not incorporate any form of sensor-based feedback, positioning accuracy depended entirely on repeatable mechanical behaviour. Consequently, the system was unable to detect nor correct inaccuracies during operation.

5.3 Discussion
This project established a practical and structured framework for a Go-playing robot. Therefore, a natural progression of this work would be to extend the system towards full autonomy, independent of the user input. Implementing a computer vision system would be a fruitful area for further work. Enabling the robot to detect the state of the board in real time and thereby dynamically adapt to changes in the environment. Further work should also be carried out to integrate a pre-existing Go AI engine to enhance the capabilities of the system. By combining perception with decision-making, the robot could autonomously play by selecting optimal moves based on the current board state provided by the vision system. It is safe to say that considerably more work needs to be done until an autonomous robot that can master the ancient game of Go can be achieved.

## 6 Acknowledgements

The author would like to thank their supervisor, Massimiliano Zecca, for their guidance, support, and valuable feedback throughout the duration of this project. The author would also like to thank the laboratory technician, David King, for his assistance in providing components and access to laboratory facilities for experimental work. Appreciation is extended to Brijesh Gurav for manufacturing the components using the 3D printing facilities at Wolfson School, and to David Wayment for coordinating the ordering of parts and providing updates on their delivery. Last but not least, the author would like to thank Emma Taylor for her invaluable feedback and advice on the writing of this report.

## 7 References

[1] “Informatical Analysis of GO, Part 1: Evolutionary changes of board size,” IEEE Conference
Publication | IEEE Xplore, Aug. 01, 2020. https://ieeexplore.ieee.org/abstract/document/9231758
[2] H. Matsubara, H. Iida, and R. Grimbergen, “Natural developments in game research,” ICGA Journal, vol. 19, no. 2, pp. 103–112, Jun. 1996, doi: 10.3233/icg-1996-19208.
[3] M. Sousa and E. Bernardo, “Back in the game,” in Communications in computer and information science, 2019, pp. 72–85. doi: 10.1007/978-3-030-37983-4_6.
[4] M. J. Rogerson, M. Gibbs, and W. Smith, “‘I Love All the Bits,’” ACM Digital Library, pp. 3956– 3969, May 2016, doi: 10.1145/2858036.2858433.
[5] Sensetime, “SenseTime Unveils SenseRobot Go: The Second AI-Powered Board Game Robot Joins the SenseRobot Family-News and Stories-SenseTime,” Sensetime.com, 2023. https://www.sensetime.com/en/news-detail/51166774?categoryId=1072

[6] P. K. Rath, N. Mahapatro, P. Nath, and R. Dash, “Autonomous Chess Playing Robot,” IEEE Xplore, Oct. 01, 2019. https://ieeexplore.ieee.org/document/8956389
[7] Pawel Kolosowski, A. Wolniakowski, and Kanstantsin Miatliuk, “Collaborative Robot System for Playing Chess,” Jul. 2020, doi: https://doi.org/10.1109/msm49833.2020.9202398.
[8] D. Springwald, “iGoBot - Daniel Springwalds Blog * Basteln mit Daniel,” Springwald.de, 2018. https://blog.springwald.de/post/2018/iGoBot
[9] C. Matuszek et al., “Gambit: An autonomous chess-playing robotic system,” IEEE Xplore, pp. 4291–4297, May 2011, doi: 10.1109/icra.2011.5980528.
[10] T. T. Mac, T.-N. Dam, T. Tri, Ly Hoang Hiep, and T.-D. Nguyen, “The Development of an Intelligent Robot Arm Playing chess with Human-Robot Interaction,” IEEE Conference Publication | IEEE Xplore, Dec. 2023, doi: https://doi.org/10.1109/ichst59286.2023.10565356.
[11] K.-L. Su, “Implementation of the chess game artificial intelligent using mobile robots,” IEEE
Conference Publication | IEEE Xplore, Dec. 01, 2014.
https://ieeexplore.ieee.org/document/7044846 (accessed Apr. 09, 2026).
[12] D. Silver et al., “Mastering the game of Go with deep neural networks and tree search,” Nature, vol. 529, no. 7587, pp. 484–489, Jan. 2016, doi: https://doi.org/10.1038/nature16961.
[13] D. J. Wu, “Accelerating Self-Play Learning in Go,” arXiv.org, Feb. 27, 2019. https://arxiv.org/abs/1902.10565
[14] S. Surati, S. Hedaoo, T. Rotti, V. Ahuja, and N. Patel, “Pick and Place Robotic Arm: A Review Paper.” Accessed: Apr. 20, 2026. [Online]. Available: https://www.irjet.net/archives/V8/i2/IRJET-V8I2311.pdf?
[15] A. Antonov, “Parallel–Serial Robotic Manipulators: A Review of Architectures, Applications, and Methods of Design and Analysis,” Machines, vol. 12, no. 11, p. 811, Nov. 2024, doi: https://doi.org/10.3390/machines12110811.
[16] Yogeshwarappa.T, Yogeshwarappa.T, Yogeshwarappa.T, and Yogeshwarappa.T, “AN OVERVIEW OF ROBOTICS AND AUTOMATION IN MODERN INDUSTRY,” IJCRT - International Journal of Creative Research Thoughts (IJCRT), vol. 8, no. 12, pp. 3609–36193609–3619, Dec. 2020, Accessed: Apr. 20, 2026. [Online]. Available: https://ijcrt.org/viewfull.php?p_id=IJCRT2012408
[17] S. Kaewkorn, C. Joochim, P. Keeratiwintakorn, and A. Kunapinun, “Development of Pick and Place Delta Robot,” Advances in Intelligent Systems and Computing, pp. 475–486, doi: 10.1007/978-3-030-40271-6_47.
[18] P. Kushwaha, J. Kumar, D. Ajit, A. Chauhan, N. Jain, and A. Verma, “Design and Fabrication of Industrial Pick and Place Delta Robot,” in Unraveling New Frontiers and Advances in Bioinformatics, 2024, pp. 409–423. doi: 10.1007/978-981-97-7123-3_18.
[19] A. elassal, M. abdelaal, Mohmad Osama, and Hager elhnidy, “low-cost parallel delta robot for a pick-and-place application with the support of the vision system.,” e-Prime, advances in electrical engineering, electronics and energy, pp. 100518–100518, Mar. 2024, doi: https://doi.org/10.1016/j.prime.2024.100518.

[20] S. Thatere, P. Arora, Y. Sharma, R. Kumar, and R. G. Mishra, “Design and Implementation of a Gantry Robot for Pick and Place Mechanism with Obstacle Detection using Programmable Logic Controller,” Zenodo, Jun. 2016, doi: https://doi.org/10.5281/zenodo.161331.
[21] G. S. Sharath, N. Hiremath, and G. Manjunatha, “Design and analysis of gantry robot for pick and place mechanism with Arduino Mega 2560 microcontroller and processed using pythons,” Materials Today: Proceedings, vol. 45, pp. 377–384, 2021, doi: https://doi.org/10.1016/j.matpr.2020.11.965.
[22] “DEVELOPMENT OF A CARTESIAN ROBOT WITH IMAGE PROCESSING AND GRASP DETECTION -SMART 2023 - EASD Procedia,” Eccomas Proceedia, 2023. https://www.eccomasproceedia.org/conferences/thematic-conferences/smart-2023/9872 (accessed Apr. 20, 2026).
[23] S. F. Noshahi, A. Farooq, M. Irfan, T. Ansar, and N. Chumuang, “Design and Fabrication of an Affordable SCARA 4-DOF Robotic Manipulator for Pick and Place Objects,” 2019 14th International Joint Symposium on Artificial Intelligence and Natural Language Processing (iSAI-NLP), Oct. 2019, doi: https://doi.org/10.1109/isai-nlp48611.2019.9045203.
[24] W.-B. Li, G.-Z. Cao, X.-Q. Guo, and S.-D. Huang, “Development of a 4-DOF SCARA robot with 3R1P for pick-and-place tasks,” IEEE Xplore, Dec. 01, 2015. https://ieeexplore.ieee.org/document/7398909 (accessed Nov. 17, 2021).
[25] M. A. González-Palacios, M. A. Garcia-Murillo, and M. González-Dávila, “A novel tool to optimize the performance of SCARA robots used in pick and place operations,” Journal of Mechanical Science and Technology, vol. 35, no. 10, pp. 4715–4726, Sep. 2021, doi: https://doi.org/10.1007/s12206-021-0937-x.

## 8 Appendix

Table 4. Bill of materials

Item | Quantity | Cost | Supplier | Reference
battery box | 1 | £ 2,41 | RS components
Batteries | 8 | £ 4,39 | RS components
Servo motors | 2 | £ 22,02 | Farnell | SER0044
Micro servo | 1 | £ 4,32 | Farnell | SER0039

Arduino Cloud Sketch
https://app.arduino.cc/sketches/9923f9a1-adf1-4cbb-a925-ab8f35f5f6f3?view-mode=preview

Project GitHub Repository

https://github.com/umbelinapia/GoPlayingRobot

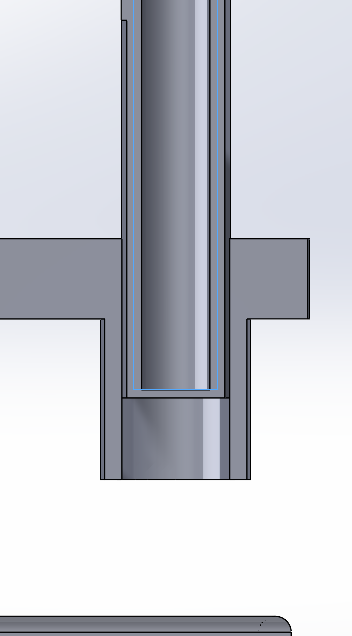
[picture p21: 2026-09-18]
evidence/high position.png

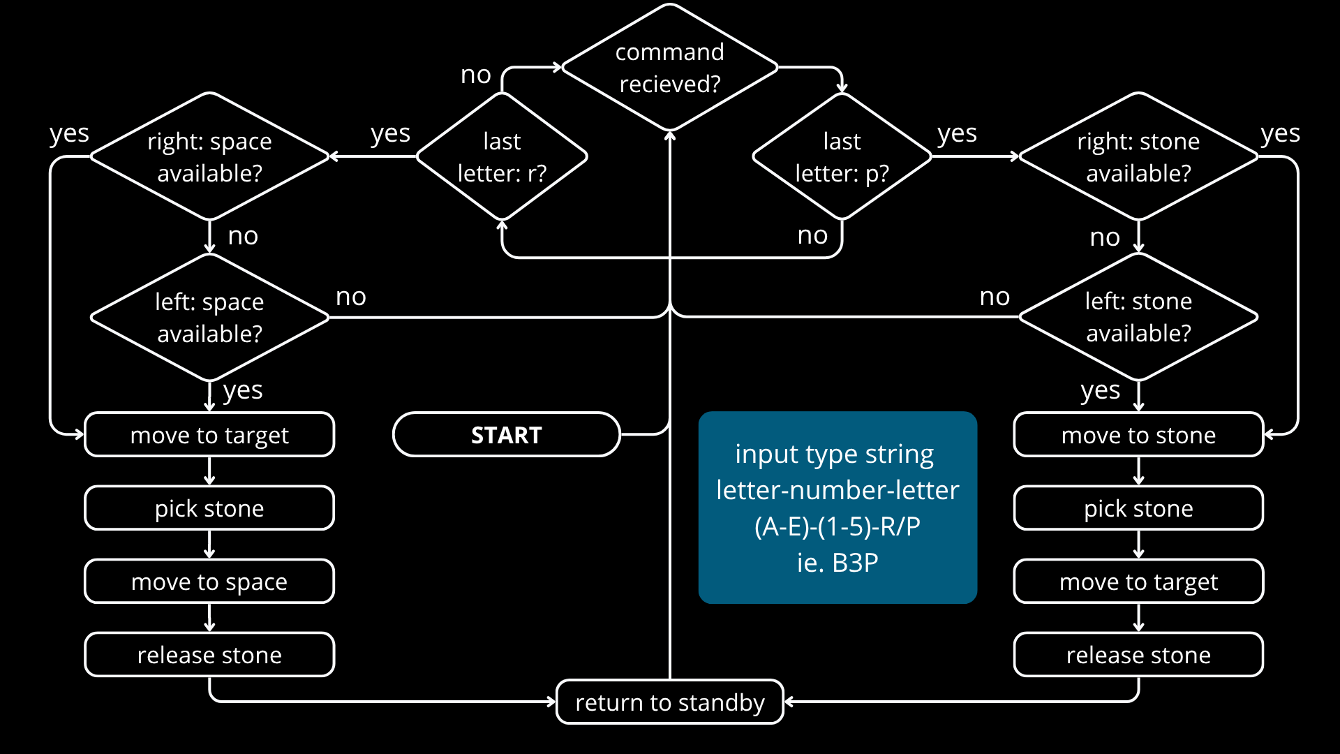
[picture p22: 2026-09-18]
evidence/command_flowchart.png

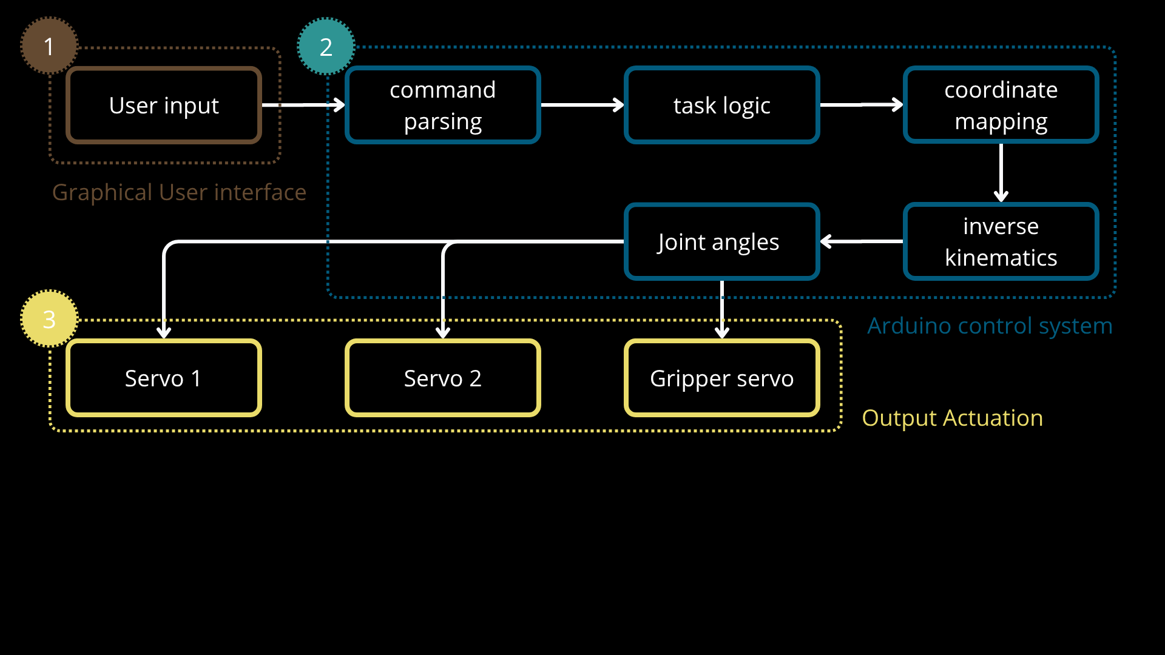
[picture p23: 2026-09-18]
evidence/software_dataflow_diagram.png

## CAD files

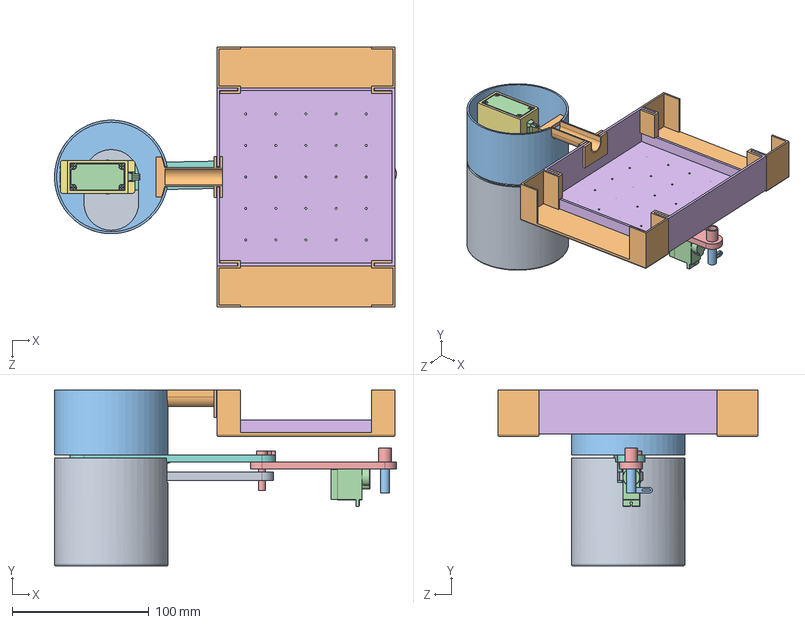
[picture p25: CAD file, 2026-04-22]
hardware/assembly/assembly.SLDASM
249.8 x 128.5 x 190.1 mm
base frame
board
servo long straight horn
DSS-M15S 270° Servo x 3
base protection
connection cable
top protection
link 1 revisited
pulley attachment
Servo horn v2.step
link 2
MG90servo_body
magnet carrier
stone box x 2
belt

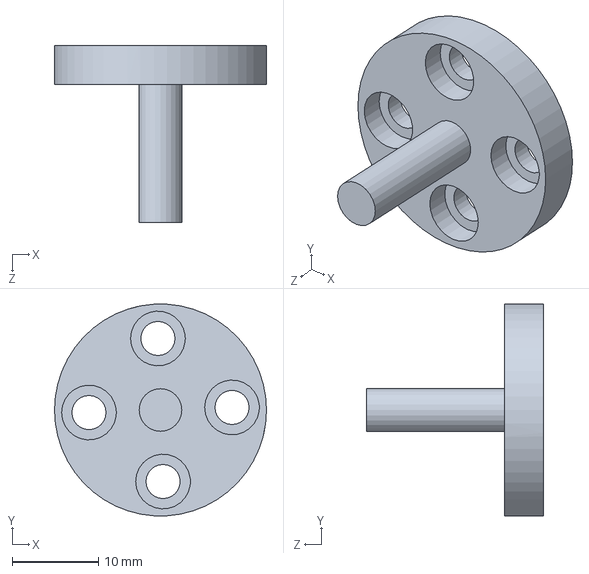
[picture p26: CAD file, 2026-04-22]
hardware/parts/pulley attachment.SLDPRT
24.6 x 24.6 x 20.5 mm

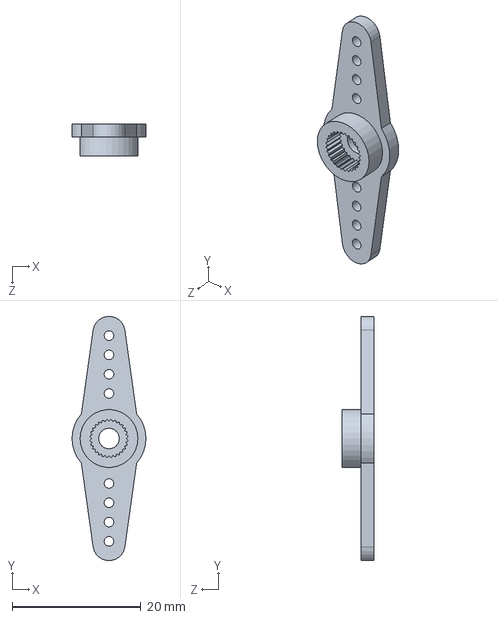
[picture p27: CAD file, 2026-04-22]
hardware/parts/servo long straight horn.SLDPRT
11.5 x 38.0 x 5.00 mm

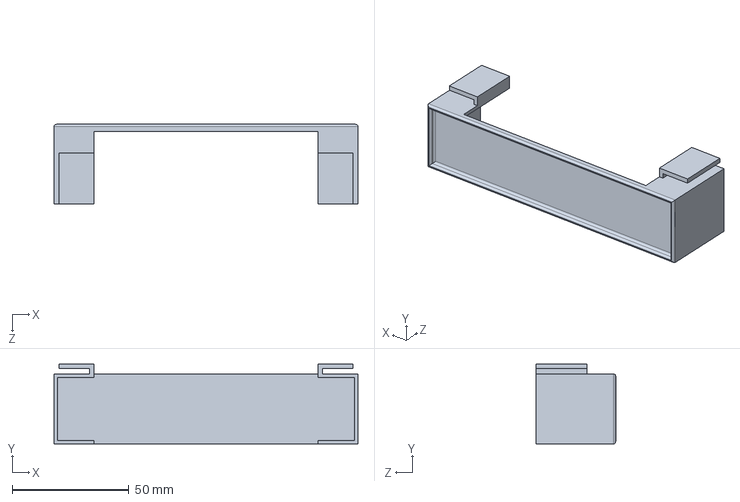
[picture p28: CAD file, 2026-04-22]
hardware/parts/stone box.SLDPRT
130.0 x 34.2 x 34.0 mm

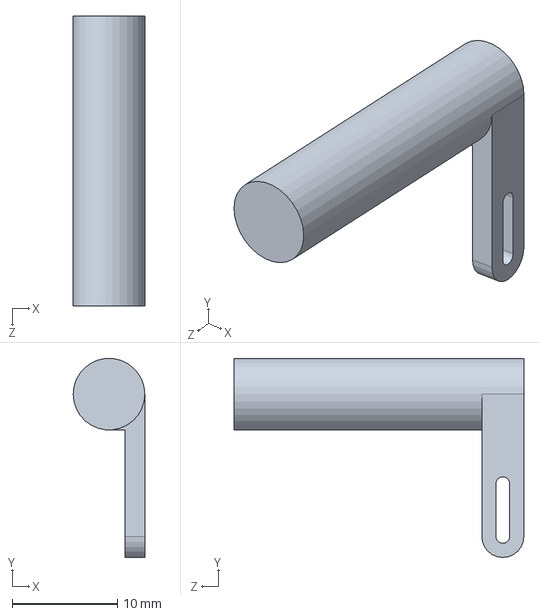
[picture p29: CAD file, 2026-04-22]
hardware/parts/magnet carrier.SLDPRT
6.80 x 18.9 x 27.5 mm

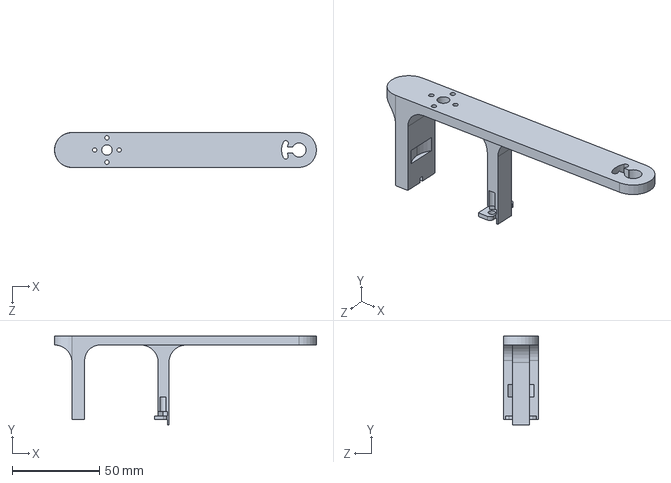
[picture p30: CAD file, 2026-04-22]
hardware/parts/link 1 revisited.SLDPRT
150.0 x 50.7 x 20.0 mm

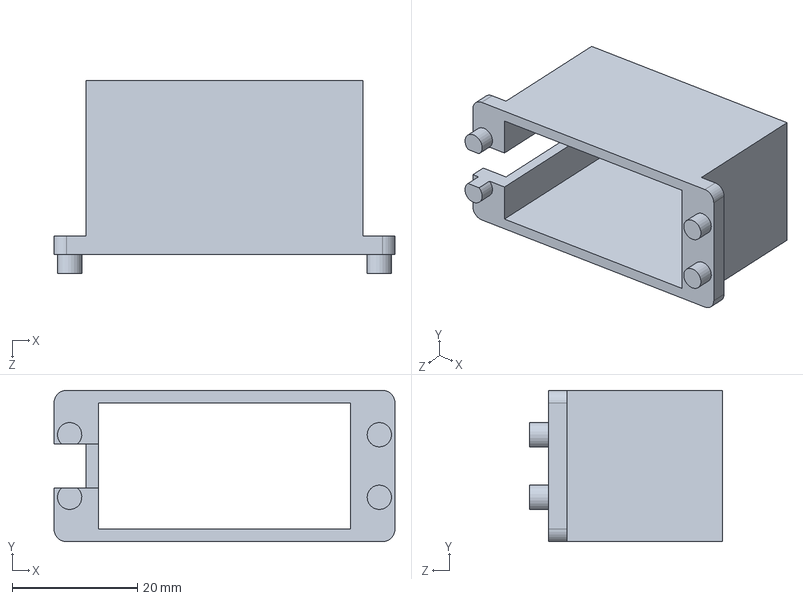
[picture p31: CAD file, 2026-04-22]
hardware/parts/base frame.SLDPRT
54.5 x 24.2 x 30.8 mm

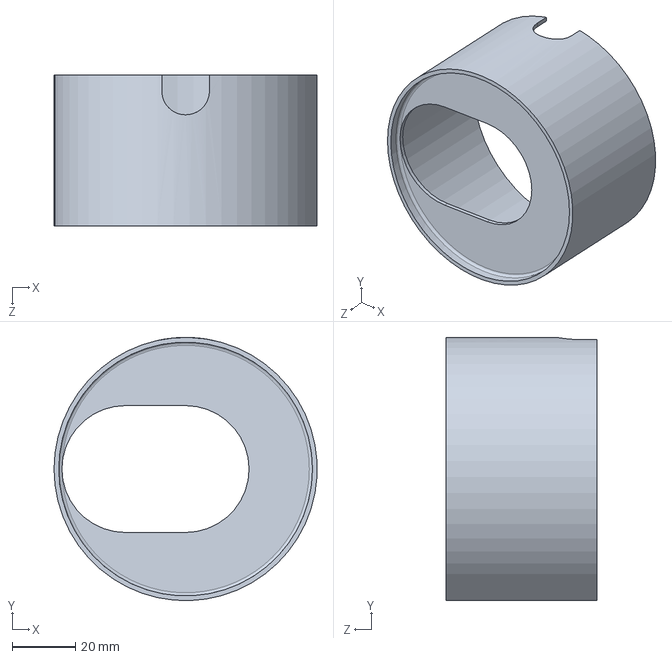
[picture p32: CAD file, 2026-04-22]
hardware/parts/base protection.SLDPRT
82.9 x 83.0 x 47.5 mm

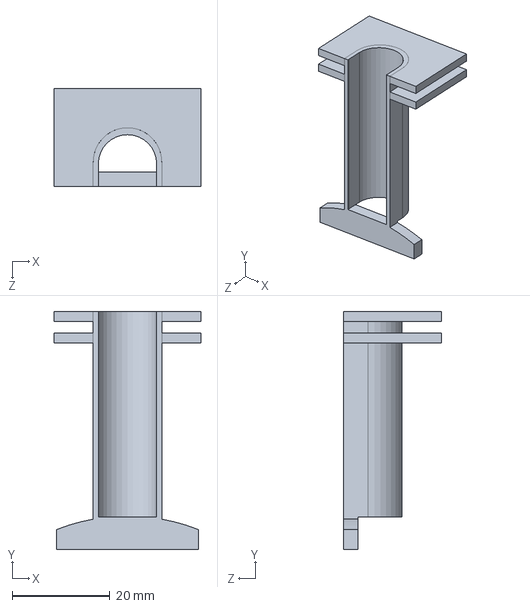
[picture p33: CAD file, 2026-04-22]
hardware/parts/connection cable.SLDPRT
30.0 x 48.6 x 20.0 mm

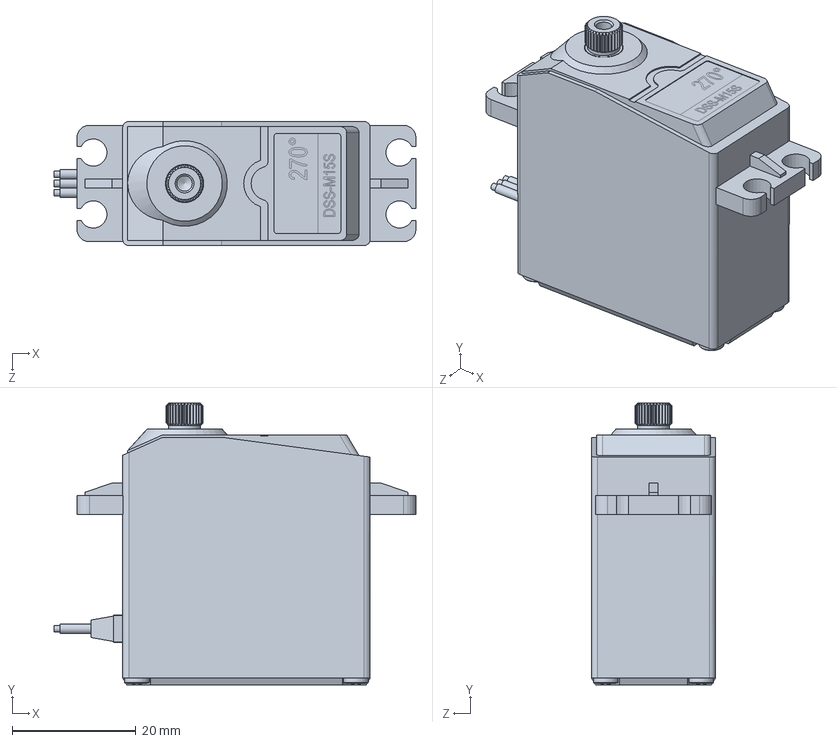
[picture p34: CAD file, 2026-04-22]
hardware/parts/DSS-M15S 270° Servo.SLDPRT
58.5 x 45.5 x 20.1 mm

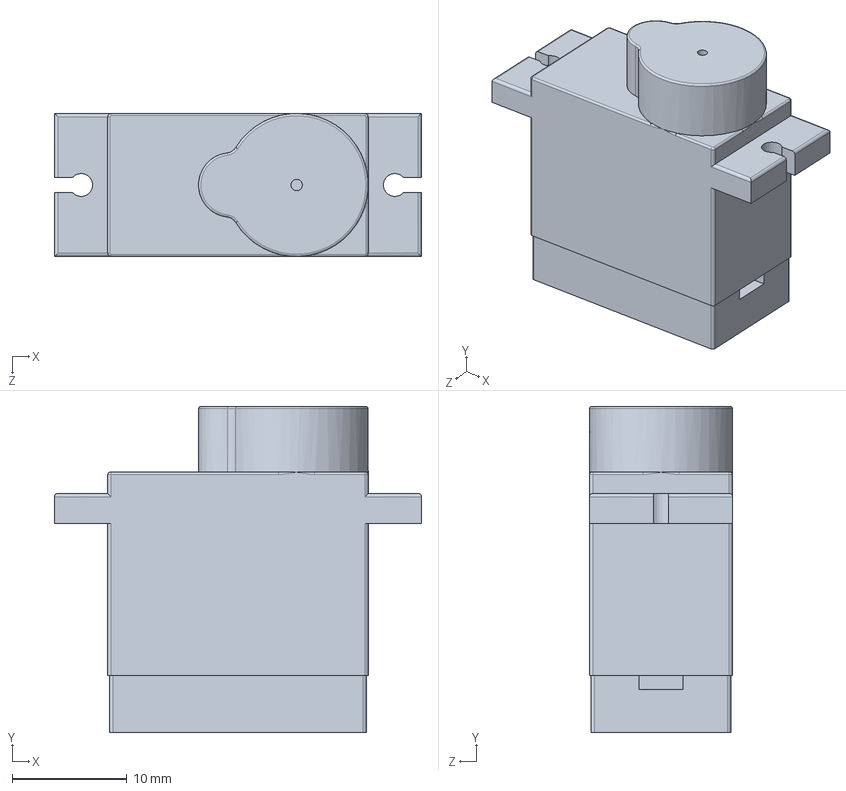
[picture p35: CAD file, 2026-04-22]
hardware/parts/MG90servo_body.SLDPRT
32.0 x 28.5 x 12.5 mm

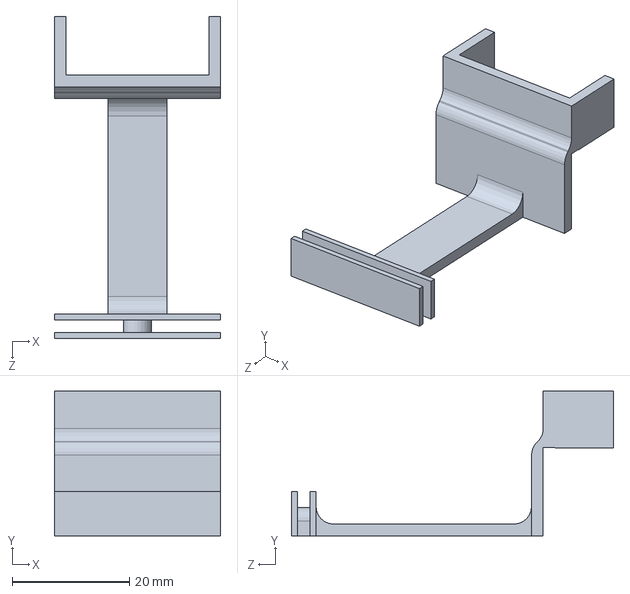
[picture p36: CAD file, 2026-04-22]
hardware/parts/connection.SLDPRT
28.4 x 24.7 x 55.0 mm

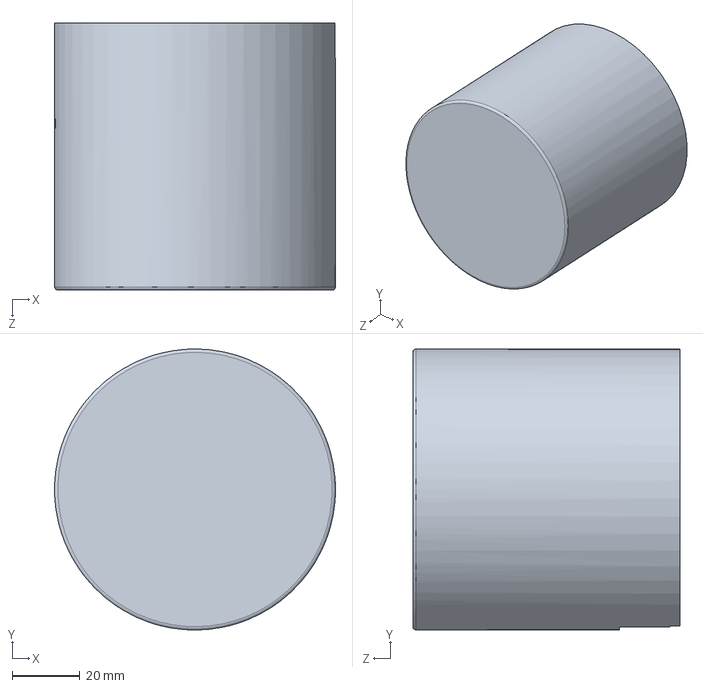
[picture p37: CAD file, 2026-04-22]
hardware/parts/top protection.SLDPRT
83.0 x 83.0 x 79.0 mm

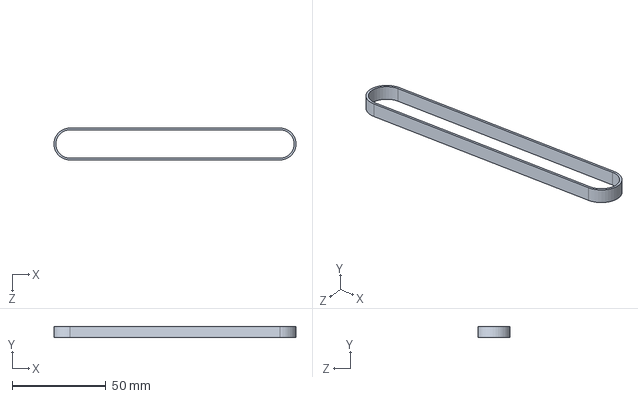
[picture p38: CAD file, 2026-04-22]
hardware/parts/belt.SLDPRT
128.9 x 6.00 x 17.0 mm

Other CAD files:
hardware/parts/Servo horn v2.step.SLDPRT
hardware/parts/board.SLDPRT
hardware/parts/link 2.SLDPRT
hardware/assembly/drawing.SLDDRW

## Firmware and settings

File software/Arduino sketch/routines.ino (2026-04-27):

#include "arduino_secrets.h"

#include <Servo.h>
#include <math.h>
#include "coordinates.h"
#include "serial_commands.h"
#include "tasks.h"

Servo s1;  // Joint 1
Servo s2;  // Joint 2
Servo s3;  // gripper

const int US_AT_0   = 500;
const int US_AT_270 = 2500;

float x, y;

const int EE_UP_ANGLE    = 60;
const int EE_HOVER_ANGLE = 95;
const int EE_DOWN_ANGLE  = 130;
int currentEE = EE_HOVER_ANGLE;  

const float L1 = 110.0f;
const float L2 =  90.0f;

const float JOINT1_OFFSET_X = 0.0f;
const float JOINT1_OFFSET_Y = 140.0f;


int SERVO1_OFFSET = 48;   // degrees added to computed servo angle
int SERVO2_OFFSET = 158;
int SERVO1_DIR    = +1;  // +1 or -1 if reversed
int SERVO2_DIR    = -1;

const int STEP_DEG = 1;      
const int STEP_DELAY_MS = 30; 

int currentS1 = 0; 
int currentS2 = 0;

int angleToUs270(int a) {
  a = constrain(a, 0, 270);
  return map(a, 0, 270, US_AT_0, US_AT_270);
}

void writeServo270(Servo &s, int deg270) {
  s.writeMicroseconds(angleToUs270(deg270));
}

void endEffectorUp()    { moveEndEffectorTo(EE_UP_ANGLE); }
void endEffectorHover() { moveEndEffectorTo(EE_HOVER_ANGLE); }
void endEffectorDown()  { moveEndEffectorTo(EE_DOWN_ANGLE); }

void moveEndEffectorTo(int angleDeg) {
  angleDeg = constrain(angleDeg, 0, 160);   
  s3.write(angleDeg);                     
  currentEE = angleDeg;

  Serial.print("End effector (s3) angle = ");
  Serial.println(currentEE);
}

void moveServosSlow(int targetS1, int targetS2) {
  targetS1 = constrain(targetS1, 0, 270);
  targetS2 = constrain(targetS2, 0, 270);

  Serial.print("Servo angles (deg): s1=");
  Serial.print(targetS1);
  Serial.print(", s2=");
  Serial.println(targetS2);

  while (currentS1 != targetS1 || currentS2 != targetS2) {
    if (currentS1 < targetS1) currentS1 = min(currentS1 + STEP_DEG, targetS1);
    else if (currentS1 > targetS1) currentS1 = max(currentS1 - STEP_DEG, targetS1);

    if (currentS2 < targetS2) currentS2 = min(currentS2 + STEP_DEG, targetS2);
    else if (currentS2 > targetS2) currentS2 = max(currentS2 - STEP_DEG, targetS2);

    writeServo270(s1, currentS1);
    writeServo270(s2, currentS2);
    delay(STEP_DELAY_MS);

  }
}

bool solveIK(float x, float y, float &theta1_deg, float &theta2_deg, bool elbowUp) {
  float r2 = x*x + y*y;
  float r  = sqrt(r2);
  float theta2;   

  if (r > (L1 + L2) || r < fabs(L1 - L2)) return false;

  float c2 = (r2 - L1*L1 - L2*L2) / (2.0f * L1 * L2);
  c2 = constrain(c2, -1.0f, 1.0f);

  theta2 = acos(c2); 

  float s2 = sin(theta2);
  float k1 = L1 + L2 * c2;
  float k2 = L2 * s2;

  float theta1 = atan2(y, x) - atan2(k2, k1);

  theta1_deg = theta1 * 180.0f / M_PI;
  theta2_deg = theta2 * 180.0f / M_PI;

  Serial.print("IK joints (deg): theta1=");
  Serial.print(theta1_deg);
  Serial.print(", theta2=");
  Serial.println(theta2_deg);
  
  return true;
}

bool moveToBoardXY(float xb, float yb, bool elbowUp=true) {
  // Board -> Joint1 frame
  float x = xb - JOINT1_OFFSET_X;
  float y = yb + JOINT1_OFFSET_Y;

  float t1, t2;
  
  if (!solveIK(x, y, t1, t2, elbowUp)) {
    Serial.println("Invalid IK solution");
    return false;
  }

  int s1 = (int)round(SERVO1_OFFSET + SERVO1_DIR * t1);
  int s2 = (int)round(SERVO2_OFFSET + SERVO2_DIR * t2);

  s1 = constrain(s1, 0, 270);
  s2 = constrain(s2, 0, 270);

  moveServosSlow(s1, s2);
  return true;
}


void setup() {
  Serial.begin(115200);

  while (!Serial) { ; }

  s3.attach(10);
  s1.attach(9);
  s2.attach(8);
  
  endEffectorHover();

  Serial.println("Ready.");
  initBoxes();
}

void loop() {
  
  readSerialCellCommand();

}

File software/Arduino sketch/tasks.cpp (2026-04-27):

#include <Arduino.h>
#include "tasks.h"
#include "coordinates.h"
#include "serial_commands.h"

extern bool moveToBoardXY(float xb, float yb, bool elbowUp);
extern void endEffectorUp();
extern void endEffectorHover();
extern void endEffectorDown();

extern const float grid[5][5][2];
extern const float left_box[5][2];
extern const float right_box[5][2];

const int BOX_SLOTS = 5;

bool rightBoxOccupied[BOX_SLOTS];
bool leftBoxOccupied[BOX_SLOTS];

void initBoxes() {
  for (int i = 0; i < BOX_SLOTS; i++) {
    rightBoxOccupied[i] = false;
    leftBoxOccupied[i] = true;
  }
}

bool getNextRightStone(float &x, float &y, int &slotIndex) {
  for (int i = 0; i < BOX_SLOTS; i++) {
    if (rightBoxOccupied[i]) {
      x = right_box[i][0];
      y = right_box[i][1];
      slotIndex = i;
      return true;
    }
  }
  return false;
}

bool getNextLeftStone(float &x, float &y, int &slotIndex) {
  for (int i = 0; i < BOX_SLOTS; i++) {
    if (leftBoxOccupied[i]) {
      x = left_box[i][0];
      y = left_box[i][1];
      slotIndex = i;
      return true;
    }
  }
  return false;
}

bool getNextEmptyLeftBox(float &x, float &y, int &slotIndex) {
  for (int i = 0; i < BOX_SLOTS; i++) {
    if (!leftBoxOccupied[i]) {
      x = left_box[i][0];
      y = left_box[i][1];
      slotIndex = i;
      return true;
    }
  }
  return false;
}

bool getNextEmptyRightBox(float &x, float &y, int &slotIndex) {
  for (int i = 0; i < BOX_SLOTS; i++) {
    if (!rightBoxOccupied[i]) {
      x = right_box[i][0];
      y = right_box[i][1];
      slotIndex = i;
      return true;
    }
  }
  return false;
}

void PlaceStone(float xb, float yb) {
  float sx, sy;
  int slotIndex;

  if (!getNextRightStone(sx, sy, slotIndex)) {
    Serial.println("No stones left in right box, checking left box...");
    if (!getNextLeftStone(sx, sy, slotIndex)) {
      Serial.println("No stones left in either box.");
      return;
    }

    Serial.print("Picking from left box F");
    Serial.println(slotIndex + 1);
    leftBoxOccupied[slotIndex] = false;
  } else {
    Serial.print("Picking from right box G");
    Serial.println(slotIndex + 1);
    rightBoxOccupied[slotIndex] = false;
  }

  moveToBoardXY(sx, sy, true);
  delay(2000);

  endEffectorDown();
  delay(2000);

  endEffectorHover();
  delay(2000);

  moveToBoardXY(xb, yb, true);
  delay(2000);

  endEffectorUp();
  delay(2000);

  Serial.println("Stone placed.");
    
  Serial.println("Returning to STANDBY...");
  handleCellCommand("STANDBY");  
  delay(2000);
}

void RemoveStone(float xb, float yb) {
  float dropX, dropY;
  int slotIndex;

  moveToBoardXY(xb, yb, true);
  delay(2000);

  endEffectorDown();
  delay(2000);

  endEffectorHover();
  delay(2000);

  if (getNextEmptyLeftBox(dropX, dropY, slotIndex)) {
    Serial.print("Dropping in left box F");
    Serial.println(slotIndex + 1);

    moveToBoardXY(dropX, dropY, true);
    delay(2000);

    leftBoxOccupied[slotIndex] = true;
  }
  else if (getNextEmptyRightBox(dropX, dropY, slotIndex)) {
    Serial.print("Dropping in right box G");
    Serial.println(slotIndex + 1);

    moveToBoardXY(dropX, dropY, true);
    delay(2000);

    rightBoxOccupied[slotIndex] = true;
  }
  else {
    Serial.println("No empty box slots available.");
    return;
  }
  
  endEffectorUp();

  Serial.println("Stone removed.");
  
  // Return to standby
  Serial.println("Returning to STANDBY...");
  handleCellCommand("STANDBY");  
  delay(2000);
}

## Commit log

2026-04-22 part drawings and assembly
    [DSS-M15S 270° Servo.SLDPRT, MG90servo_body.SLDPRT, Servo horn v2.step.SLDPRT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]
2026-04-22 Reorganize files into folders
    [DSS-M15S 270° Servo.SLDPRT, MG90servo_body.SLDPRT, Servo horn v2.step.SLDPRT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]
2026-04-27 Reorganise into hardware folder
    [DSS-M15S 270° Servo.SLDPRT, MG90servo_body.SLDPRT, Servo horn v2.step.SLDPRT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]
2026-04-27 Add Arduino sketches
2026-09-18 Add labeled evidence folder with project media
    Imports supporting photos, CAD renders, wiring diagrams, GUI
    screenshots, and design diagrams, with descriptive filenames and a
    README index captioning each image.
